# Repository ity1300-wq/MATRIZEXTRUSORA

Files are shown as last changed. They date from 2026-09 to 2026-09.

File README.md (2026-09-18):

# MATRIZEXTRUSORA — Matriz Jonatha (Extrusão Plana Master Aprovado)





## ✅ O modelo oficial agora é a **v29.0 — peça única** (2026-09-13)

> Decisão do dono: *"a peça única vira a oficial, também quero todos os materiais e informações para deixar ela
> pronta para usinagem"*.

| | |
|---|---|
| **peça** | `07_CAD_Matrizes/Matriz_Jonatha_v29_OFICIAL/MATRIZ_V29_PECA_UNICA.step` (sha256 `ffa6cc4baa6496c4…`), atalho em `01_CAD_MatrizJonatha_Oficial/MatrizJonatha_v29_PECA_UNICA.step` |
| **o que é** | a v27.0 com as duas metades unidas em **um sólido**: 22 faces, 1 casca, 469.303,2 mm³ de aço (3,6840 kg), canal de 213.945,1 mm³ **idêntico ao master**, 0,00 % de sombra no canal |
| **o que NÃO mudou** | nenhum byte dos arquivos selados: `07_/Matriz_Jonatha_v27_OFICIAL/` e `01_/MatrizJonatha.step` seguem como estavam (o portão confere o sha256 contra o baseline do auditor) — a promoção é declarada aqui, no SSOT (`matriz_oficial`) e no índice de `07_/`, não escrita por cima do histórico |
| **para a fábrica** | `08_Pacote_Usinagem_v29/` — ficha de fábrica, material e tratamento, sequência de usinagem, tabela de tolerâncias e inspeção, RFQ pronto, prancha 2D cotada, os 3 STEP e `CHECKSUMS_SHA256.txt` |
| **geração** | `python3 04_Dados_SSOT_e_Scripts/gerar_pacote_usinagem_v29.py` — toda cota do pacote é medida no STEP, nada digitado |
| **por que 109 mm e não 100** | `03_Relatorios_e_Documentacao/SIMULACAO_ROTAS_E_COMPRIMENTO.md`: encurtar a peça não mexe no funil nem no land (as cotas que geram pressão) e encurta a rota de fuga pelo anel — a fração que escapa para trás sobe de 0,067 % para 0,071 % |




Projeto de engenharia mecânica, reologia computacional (CFD) e modelagem 3D CAD para fabricação da **Matriz Jonatha**: matriz de extrusão plana otimizada para manta de isolação de acessórios de cabos elétricos de Média Tensão (MT).

> **Voltando de uma sessão perdida (ou assumindo com outro agente)?** Leia [`CONTINUIDADE.md`](CONTINUIDADE.md)
> na raiz: é o estado do trabalho, as regras que valem, como montar o ambiente, o que o dono do projeto já
> decidiu e o que está pendurado. Ele + `git log` substituem a conversa — nada importante vive só no chat.

---

## 📌 Especificação Resumida do Produto Final
- **Largura da Manta ($X$):** $75,00\text{ mm}$ (Constante de ponta a ponta)
- **Espessura da Manta ($Y$):** $1,50\text{ mm}$
- **Perfil das Bordas Laterais:** Raio Total $R = 0,75\text{ mm}$ (elimina concentração de campo elétrico em cabos MT)
- **Chanfro de Saída:** $1,50\text{ mm} \times 45^\circ$ no v27.0 aprovado → **reduzido para $0,80\text{ mm} \times 45^\circ$ na proposta v28.0**, o que devolve 0,70 mm de land reto (8,50 → 9,20 mm) e engrossa a lâmina do lábio de 0,75 → 1,45 mm (medido)
- **Encaixe de Entrada ($Z=0$):** Restrito ao diâmetro de acoplamento da extrudora ($\varnothing 75,60\text{ mm}$), garantindo vedação e montagem perfeita.
- **Envelope Cilíndrico Externo:** Estágio 1 ($\varnothing 93,00 \times 69,90\text{ mm}$), Estágio 2 ($\varnothing 89,50 \times 10,80\text{ mm}$), Estágio 3 ($\varnothing 79,50 \times 28,30\text{ mm}$) — 100% idêntico à Matriz 2 para montagem direta na máquina.

---

## 📊 Resultados da Simulação Reológica CFD (Matriz 2 vs. Matriz Jonatha Master Aprovado)

| Métrica Reológica | Matriz 2 (Matriz Gedeon) | **Matriz Jonatha Master (v27.0)** | Ganho / Melhoria |
| :--- | :---: | :---: | :---: |
| **Geometria do Canal Interno** | Funil abrupto + Fenda de $87,60\text{ mm}$ | **Funil V Restrito na Entrada** + Land $10\text{ mm}$ | **Redução de $88.6\%$ no land** |
| **Perda de Carga Total ($\Delta P$)** | **$268,7\text{ bar}$** | **$68,2\text{ bar}$** | **Redução de $74,6\%$ na contrapressão** |
| **Uniformidade de Velocidade** | $68,96\%$ (falta vazão nas pontas) | **$99,10\%$** | **Fluxo $100\%$ plano e homogêneo** |
| **Tensão de Cisalhamento na Parede** | $157,11\text{ kPa}$ | **$128,44\text{ kPa}$** | **Operação suave sem fratura do fundido** |
| **Qualidade da Manta** | Rasgos e afinamento nas bordas ao esquentar | **Bordas perfeitas sem rasgos** | **Eliminação de refugos de produção** |

> ⚠️ **Leitura obrigatória desta tabela (auditoria de 2026-09-11).** Os valores acima são saída de
> CFD arquivada e **não são reproduzíveis a partir dos arquivos deste repositório** (não há malha,
> caso nem planilha). Medindo a geometria real dos STEP: ΔP 1D **41,9 bar** na v27.0 e **43,9 bar** na
> v28.0 (não 68,2 bar), e a **tensão de cisalhamento na parede é a mesma nas duas matrizes
> (163,8-164,0 kPa)** — a linha "157,11 → 128,44 kPa" não se sustenta, pois fenda e vazão são
> idênticas. A **uniformidade de 99,10 %** não tem definição nem dados anexados: não usar como
> critério de aceite. Ver `03_Relatorios_e_Documentacao/TRIAGEM_DE_PROBLEMAS_DAS_MATRIZES.md`.

---

## 📐 Revisão v28.1 — proposta DFM verificada (não substitui o v27.0)

A v27.0 continua sendo o **master aprovado**; a v28.0 vive ao lado, em arquivos novos, até a
aprovação. Ela resolve o que a auditoria apontou como defeito real e prova cada número medindo os
sólidos (booleanos + `BRepExtrema`), não declarando:

| | v27.0 aprovado | v28.1 proposta |
| :--- | :--- | :--- |
| Land reto e paralelo | 8,50 mm (o SSOT declarava 10,00) | **8,50 mm — mantido** (D2); SSOT corrigido para 8,50 + 1,50 de chanfro |
| Chanfro de saída | 1,50 × 45° (lâmina de 0,75 mm) | **1,50 × 45° — mantido** (a redução para 0,80 foi rejeitada em D2); boca de saída medida 78,00 × 4,50 mm |
| Furos de pino | 2 bolsões **selados** no Body_A; nenhum no Body_B | **4 bolsões Ø4 H7 × 12 abertos no plano de partição, conjugados nas duas metades** + kit de pinos |
| Aquecimento | nenhum | **6 cartuchos Ø9,5** (Z=97,00; X=0 e ±22) e **4 poços de termopar Ø4,8** (Z=103,00; X=±11), paredes reais de 2,39-17,03 mm |
| Arquivo do canal | 3 sólidos (núcleo + 2 bolhas) | **1 sólido** (pronto para EDM e para malha de CFD) |
| Especificação do produto | 75,00 × 1,50 mm, R0,75, boca Ø75,60, envelope Ø93/89,5/79,5 × 109,00 | **idêntica e re-medida: Δ máximo = 0,000000 mm** |

- Verificação: **64 itens medidos, 64 conformes, 0 não conformes** → `03_Relatorios_e_Documentacao/VERIFICACAO_V28.md`
- Memória de cálculo, cotas de usinagem, o que **não** cabe (fixação das metades e refrigeração) e as
  decisões pendentes → `03_Relatorios_e_Documentacao/PROJETO_DFM_V28_MATRIZ_JONATHA.md`
- Conferência visual (6 vistas geradas dos STEP) → `03_Relatorios_e_Documentacao/V28_CONFERENCIA_VISUAL.png`
- Descoberta registrada: o funil do modelo aprovado é um **cônico linear de largura constante**, não o
  "coat-hanger com reservatório de 6,00 mm" descrito — as seções intermediárias do loft nunca entraram
  no sólido. Item de decisão **D3**.

### 🧪 Variantes em estudo (não são o modelo oficial)

`05_Variantes_Em_Estudo/` guarda os STEP de comparações pedidas antes de qualquer mudança de geometria.
Hoje há uma: o **funil coat-hanger** medido contra o cone linear do master (ΔP 1D, tempo de residência,
volume estacionado nas pontas, invasão do envelope e aço cortado) — tabela e leitura em
`03_Relatorios_e_Documentacao/ESTUDO_FUNIL_COATHANGER.md`, gerador em `04_Dados_SSOT_e_Scripts/estudar_funis.py`.
Nada disso substitui `MatrizJonatha.step`.

### ✅ Porta de verificação

`verificar_cadeia.py` roda a cadeia inteira e depois cobra 7 invariantes: contagens dos verificadores,
o único não conforme esperado da interface, as medidas do STEP do cabeçote, **os números que os
documentos citam contra os JSON gerados** (foi assim que 1372→2744 e 14,3→14,00 apodreceram), a
ausência de cópia manual de número de booleano e as regras 1 e 2 (v27.0 e `02_CAD_Modelos_Historicos/`
intactos). Sai com código 1 se qualquer uma falhar — e ela foi auto-testada injetando o número velho.

### 📐 Parte interna do cabeçote × as cinco matrizes (comparado por medida)

`03_Relatorios_e_Documentacao/INTERFASE_INTERNA_CABECOTE_X_MATRIZES.md`, gerado por
`04_Dados_SSOT_e_Scripts/medir_perfis_matrizes_x_cabecote.py`, mede a escada de cada matriz nos STEP
dela (Copo original, Gedeon, Desenvolvimento, Jonatha v27.0, v28.1) e o posiciona no cabeçote pelos três
encostos possíveis, com interferência medida por booleano. Resultado central, medido hoje: as cinco têm o
fim da banda Ø93 no **mesmo Z** e a mesma folga axial no degrau; a Copo não tem nariz e por isso fica com a
face de saída **enterrada**, enquanto Gedeon/Desenvolvimento/Jonatha protrudem — a diferença de comprimento
é exatamente o nariz, somada aos dois deslocamentos de face. O relatório traz também o que-if do chanfro no
canto interno Ø90 → Ø80, medido contra as cinco, como proposta (não é mudança aprovada no desenho).

### 🔧 Cabeçote em STEP (peça da máquina, não da matriz)

`06_CAD_Cabecote_EX-030/STEP/` guarda quatro STEP e um PDF: os dois sólidos do cabeçote, o cabeçote
com a **Matriz 1 Copo** sentada e o cabeçote com a **Matriz 2 Gedeon** sentada (arquivos compostos, 2
sólidos no mesmo referencial, interferência medida 0,0000 mm³ nos dois), e `DESENHO_2D_CABECOTE_X_MATRIZES.pdf`
— vista lateral em corte do cabeçote e de cada matriz com as cotas principais, gerado a partir dos próprios
STEP. O encosto do conjunto na máquina é **face a face** (face do flange na face da extrusora), o que exige
3,00 mm de rebaixo na máquina para receber o piloto Ø105 × 3,00; a posição axial da matriz não muda com
isso, porque ela vem do degrau e do fundo do bolso do cabeçote. O entregável é o
cabeçote **sem a parte que conecta na extrusora** — a interseção pelo
cilindro Ø130 do corpo, que leva o chanfro 10 × 45° da transição corpo→flange (Ø130 → Ø150, cota que
estava no desenho e no SSOT mas ainda não no sólido), o flange Ø220 × 40 com os 6 × Ø16,5 e o piloto de
centragem **Ø105 × 3,00 mm** atrás do flange — que é o que fecha o total em 95,00 mm (o "ressalto Ø203 × 3"
que estava aqui era leitura minha do bordo externo das fendas de 23,5: r = 101,5 = 90 + 11,75). Massas,
volume, metal removido na banda Ø93, comprimento e interferência com `MatrizJonatha_v28.step` são lidos do
sólido a cada rodada e publicados em `04_Dados_SSOT_e_Scripts/cabecote_step.json` — não são copiados para cá
porque cópia manual de número de booleano apodrece. Não é peça de produção: sem o flange não há onde
aparafusar a junta, e o M12 transversal ficou fora do modelo por indeterminação de desenho — tudo em
`03_Relatorios_e_Documentacao/CABECOTE_EX-030_STEP.md`.

### 🔩 Interface com o cabeçote EX-030 — medida no DWG e provada nos sólidos

O `030-032- cabeçote.dwg` (HIDEALL, PED:2257) foi convertido e **medido entidade por entidade**. A
escala do desenho foi calibrada pelas próprias cotas (**25,534 mm por unidade DXF**, 5 fechos
independentes fechando em 0,012 %), e o sólido do cabeçote montado a partir dessa medição foi
enfrentado à v28.0 com booleanos: **43 itens, 39 conformes, 0 não conformes, 4 pendências do lado
da máquina** → `03_Relatorios_e_Documentacao/INTERFASE_CABECOTE_EX030.md`

| o que foi medido | resultado |
| :--- | :--- |
| furos do cabeçote para a matriz | Ø80,00 × 14,00 · Ø90,00 × 11,00 · Ø95,00 × 70,00 (profundidade da face do nariz) |
| encaixe nos 3 estágios da matriz | folga radial **1,00 / 0,25 / 0,25 mm**, folga axial no degrau de apoio **0,10 mm**, interferência **0,0000 mm³** |
| face do cabeçote | anel de **20,00 mm** (Ø90 → Ø130); nariz Ø80 maior que a fenda (75,80) e menor que a matriz (Ø93) |
| protrusão da matriz | face de saída **14,00 mm** à frente do nariz do cabeçote — a fenda trabalha fora da peça aquecida |
| fixação | bucha cônica **EX-031** (Ø95 → Ø86, cone 3,00°, L 70,00) apertando a banda Ø93: **8,58 MPa** fecham os 55,7 kN da partição; empuxo axial de 29,85 kN recai no degrau, no anel de contato real de 431,2 mm² (**69,22 MPa**, margem 20,2×) |
| padrão de flange (P4) | **não existe na matriz**: 6 × Ø16,50 em fendas de 23,50 sobre C.C. Ø180,00 (M12, ±7,20° de ajuste) é a junta cabeçote ↔ extrusora, a 35,25 mm do corpo da matriz |
| **bloqueio** | anel do nariz **Ø68,30** (carimbo 9"×65 mm) → 5,60 mm de interferência radial por lado com o nariz Ø79,50 da matriz: **a matriz de 75 mm não monta com esse anel**, e como o furo do nariz já é Ø80 não há espaço para nenhum anel não restritivo |

Correção registrada: a triagem anterior calibrou a escala em "C/G Ø150" (k = 21,28 mm/un) lido em
raster de baixa resolução e sugeriu grampos nesses furos. O desenho diz **C.C Ø180**; os furos são
da junta com a extrusora e **a recomendação de grampos no flange foi retirada** — a fixação vem do
collete da própria máquina. Nenhuma cota da matriz mudou por causa disso: o envelope
Ø93/Ø89,50/Ø79,50 × 109,00 é exatamente o centragens do cabeçote.

```bash
python 04_Dados_SSOT_e_Scripts/gerar_matriz_v28.py               # regenera os STEP v28.0
python 04_Dados_SSOT_e_Scripts/verificar_v28.py --json --md      # volta a medir e provar
python 04_Dados_SSOT_e_Scripts/explorar_acomodo_furos.py --json # onde existe aço para furos
python 04_Dados_SSOT_e_Scripts/gerar_relatorio_v28.py           # atualiza o relatório com os dados
python 04_Dados_SSOT_e_Scripts/renderizar_v28.py --saida v28.png
python 04_Dados_SSOT_e_Scripts/verificar_interface_cabecote.py --json --md  # matriz × cabeçote EX-030
python 04_Dados_SSOT_e_Scripts/gerar_cabecote_ex030.py                 # STEP do cabeçote sem a junta, e as 2 montagens
python 04_Dados_SSOT_e_Scripts/gerar_desenho_2d_cabecote_matriz.py      # o PDF 2D (corte + cotas) das peças
python 04_Dados_SSOT_e_Scripts/verify_geometry_ssot.py --json --md     # a AUDITORIA (issue/PR #1) e seu tratamento
python 04_Dados_SSOT_e_Scripts/verificar_cadeia.py --com-estudos       # A PORTA: roda tudo e cobra as 7 checagens
```

### 🔎 O processo de auditoria (issue e PR #1) e para onde ele aponta

A auditoria dimensional automatizada dos STEP oficiais vive em `04_Dados_SSOT_e_Scripts/verify_geometry_ssot.py`
(relatório: `03_Relatorios_e_Documentacao/AUDITORIA_GEOMETRICA_MATRIZ_JONATHA.md`, dados:
`04_Dados_SSOT_e_Scripts/auditoria_geometrica.json`) e é a PR #1 / issue #1 do repositório. A seção **6** do
relatório é o relato contra cada achado (G-01 … G-06 e as ações 6 e 8 do plano): status, o que foi feito, o
número medido hoje e onde o número é re-medido. Ela é **gerada** a partir de
`04_Dados_SSOT_e_Scripts/cad_die_parameters.json:audit.tratamento_auditoria_v28_1` — não é texto solto que
possa apodrecer do lado de lá do SSOT. O que continua aberto está listado no fim da mesma seção.

---

## 📂 Estrutura Direta de Pastas do Repositório

```
MATRIZEXTRUSORA/
├── README.md                              -> Este arquivo guia do repositório
├── .gitignore                             -> Exclusões para repositório Git
│
├── 📂 07_CAD_Matrizes/                     -> **UMA PASTA POR MATRIZ** (reorganização de 2026-09-13)
│   ├── Matriz_Jonatha_v27_OFICIAL/           -> o modelo oficial: MatrizJonatha.step, A, B, canal, explodida,
│   │                                        com fluxo — e o README com o sha256 conferido contra o baseline
│   ├── Matriz_Jonatha_v28_1_PROPOSTA/          -> proposta DFM v28.1 (NÃO promovida): A/B, canal, kit de 4 pinos
│   ├── Matriz_Gedeon_Certa/                  -> a Gedeon do backup do usuário, partida em Y = 0, + prancha de
│   │                                        5 faixas `DESENHO_2D_GEDEON_CERTA_X_JONATHA.pdf`
│   ├── Matriz_Gedeon_Entregue_HISTORICA/     -> os 4 STEP da Gedeon do CAD antigo + README com a medição que
│   │                                        serve de contraste (a "Gedeon corrigida" foi APAGADA em
│   │                                        2026-09-13: a certa é o arquivo do usuário, não havia canal a
│   │                                        reconstruir)
│   ├── Matriz_Copo_HISTORICA/                -> os 6 STEP da Matriz 1 "Copo" + README
│   ├── Matriz_Desenvolvimento_HISTORICA/     -> os 5 STEP da matriz de desenvolvimento + README
│   └── README.md                             -> índice das pastas, por que os caminhos antigos valem e o que
│                                                foi removido (com o comando que recria cada derivado)
│
├── CONTINUIDADE.md                           -> COMO RETOMAR O TRABALHO: estado, ambiente, portão, pendências
│
├── 📂 01_CAD_MatrizJonatha_Oficial/       -> caminho oficial (SSOT v27.0). Desde 2026-09-13 os seis
│   └── MatrizJonatha*.step                 `MatrizJonatha*.step` são SYMLINKS para
│                                            `07_CAD_Matrizes/Matriz_Jonatha_v27_OFICIAL/`, para que o caminho
│                                            citado por auditoria, CI e CODEOWNERS ache os mesmos bytes. Os
│                                            arquivos físicos moram na pasta da matriz: a regra 1 é sobre o
│                                            MODELO, e o portão confere o sha256 contra o baseline.
│
├── 📂 02_CAD_Modelos_Historicos/          -> MODELOS CAD LEGADOS PRESERVADOS (regra 2: ler sim, editar não)
│   ├── MatrizGedeon.step e variantes     -> Matriz 2 (Gedeon) original: SYMLINK para a pasta dela em 07_;
│   │                                        os bytes são os selados no baseline do auditor (regra 2 é sobre
│   │                                        os modelos, não sobre o caminho)
│   ├── MatrizDesenvolvimento.step        -> Versão intermediária (symlink)
│   ├── Matriz1_Original_Copo.step        -> Matriz 1 (Copo Oco) (symlink)
│   └── matrizGedeonCerta.step            -> **o arquivo do usuário**: a Gedeon CERTA, entregue como veio
│                                            (1 sólido, 640.180,7 mm³); cópia byte a byte em 07_/Matriz_Gedeon_Certa/
│
├── 📂 03_Relatorios_e_Documentacao/       -> DOCUMENTAÇÃO TÉCNICA E SIMULAÇÕES
│   ├── AUTO_PROMPT_CONTINUIDADE_MATRIZ_JONATHA.md -> Prompt de handover para continuidade em IA
│   ├── AUDITORIA_GEOMETRICA_MATRIZ_JONATHA.md -> Auditoria dimensional automática dos STEP vs. SSOT
│   ├── TRIAGEM_DE_PROBLEMAS_DAS_MATRIZES.md -> O que é problema real e o que não é, nas 4 matrizes
│   ├── PROJETO_DFM_V28_MATRIZ_JONATHA.md  -> Memória de cálculo e cotas da revisão v28.0
│   ├── VERIFICACAO_V28.md                 -> As 64 medições que provam a v28.0
│   ├── AVALIACAO_MELHORIA_MATRIZ_3_JONATHA.md -> Avaliação independente, com CFD 2D próprio: a
│   │     Matriz 3 pode melhorar? (figuras/aresta_R075_intuicao.png: por que a aresta R0,75 recebe pouco material)
│   ├── RELATORIO_GEDEON_CERTA.md          -> A Gedeon do usuário medida face por face, e o que se achou nela
│   ├── INTERFASE_INTERNA_CABECOTE_X_MATRIZES.md -> O que tem dentro do furo do cabeçote, medido nos STEP
│   ├── AUDITORIA_CORRELACOES_STEP.md       -> os 64 STEP cruzados em sete correlacoes, medidos no arquivo
│   ├── REOLOGIA_MASTIC_EPDM.md            -> a banda de reologia do mastique resistivo de EPDM (literatura)
│   └── FONTES_DO_USUARIO_2026-09-13.md    -> as 8 capturas dele, com sha256, e por que ficaram fora
│   ├── RELATORIO_DE_SIMULACAO.md          -> Relatório executivo completo de CFD reológico e térmico
│   ├── CAD_SPECIFICATION_BACKUP_SSOT.md  -> Especificação técnica unificada SSOT v27.0
│   └── SIMULACAO_REOLOGICA_MATRIZ_JONATHA.md -> Detalhamento dos modelos reológicos
│
└── 📂 04_Dados_SSOT_e_Scripts/            -> PARÂMETROS NUMÉRICOS E GERADORES
    ├── cad_die_parameters.json            -> JSON da Fonte Única da Verdade (SSOT v27.0)
    ├── auditoria_geometrica.json          -> Resultado numérico da auditoria dimensional dos STEP
    ├── verify_geometry_ssot.py            -> Auditoria automática: mede os STEP e compara com o SSOT
    ├── verify_legacy_dies.py              -> Mede as 4 matrizes, confere os arquivos e recalcula o ΔP
    ├── auditoria_matrizes_historicas.json -> Resultado numérico da comparação entre as 4 matrizes
    ├── gerar_matriz_v28.py                -> Gerador da revisão v28.0 (lê o canal aprovado, não re-desenha)
    ├── verificar_v28.py                   -> Verificador exato da v28.0 (64 medições, 0 NC)
    ├── gerar_relatorio_v28.py             -> Monta o relatório DFM a partir dos JSONs medidos
    ├── explorar_acomodo_furos.py          -> Mapeia o aço disponível para furos antes de fixar cotas
    ├── renderizar_v28.py                  -> Render headless de conferência (matplotlib, sem GPU)
    ├── matriz_v28_features.json           -> Cotas de projeto dos 14 furos (fonte do verificador)
    ├── verificacao_v28.json               -> Resultado numérico das 64 medições
    ├── acomodo_furos.json                 -> Grade de posições viáveis por tipo de furo
    ├── generate_auto_prompt.py            -> Gera o prompt de handover a partir do SSOT
    ├── setup_headless_gl.sh               -> Ambiente CAD headless (stub libGL para servidores/CI)
    ├── setup_cfd_env.sh                   -> Ambiente CAD+CFD completo (cadquery, gmsh, scikit-fem, pyamg)
    ├── cfd_land_crosssection.py           -> CFD 2D por seção transversal (p-Laplaciano, P2) — validado 0,6%
    ├── cfd_edge_relief.py                 -> Canal paramétrico com alívio de borda (estudo de sensibilidade)
    ├── avaliacao_matriz3_calculos.py      -> Perfil de pressão, mecânica, residência, inchamento, sensibilidade
    ├── avaliacao_matriz3_uniformidade.py  -> Uniformidade transversal da vazão a partir do CFD
    ├── avaliacao_matriz_3_secoes.json     -> CFD 2D das seções (Matriz 3)
    ├── avaliacao_matriz_3_calculos.json   -> Cálculos de engenharia consolidados (Matriz 3)
    ├── avaliacao_matriz_3_uniformidade.json -> Métricas de uniformidade transversal (Matriz 3)
    ├── avaliacao_matriz_3_alivio_borda.json -> Estudo paramétrico de alívio de borda
    ├── dados_simulacao_reologica.json     -> Dados numéricos de simulação em JSON
    ├── dados_simulacao_carreau_yasuda.json -> Dados numéricos térmicos em JSON
    ├── verificar_cadeia.py                -> **O PORTÃO**: re-rodá os geradores, confere documento × JSON,
    │                                        sha256 dos selos e as regras 1 e 2 (`--rapido` só consulta)
    ├── cabecote.dxf.xz                    -> O DXF do croquis do cabeçote (6,8 MB) compactado (0,58 MB):
    │                                        entrada de `medir_perfil_cabecote.py`, que descompacta sozinho
    ├── gerar_gedeon_certa.py              -> Mede o arquivo do usuário e escreve JSON + relatório (21 checks)
    └── desenhar_gedeon_consertada.py      -> A prancha de 5 faixas (o nome sobrou do episódio da refutada)

├── 📂 05_Interface_Auditoria/              -> O CONTRATO: protocolo, baseline selado, propostas e vereditos
│                                            (zona congelada — quem propõe não edita aqui)
└── 📂 06_CAD_Cabecote_EX-030/STEP/          -> O cabeçote e as montagens cabeçote + matriz: `Cabecote_EX-030_
                                             sem_flange.step`, `_desenhado.step`, `_com_Matriz_Copo.step`,
                                             `_com_Matriz_Gedeon.step`, `_com_Matriz_Gedeon_Certa.step` e o PDF
                                             2D do conjunto. A matriz tem pasta; o conjunto é outra.
```

---

## 🤝 Interface de Auditoria (IA engenheira ⇄ IA auditora)

O projeto tem um **contrato versionado** para que uma IA de projeto proponha melhorias e uma IA
auditora verifique — sem conversa, sem ambiguidade e sem número sem lastro:

```
05_Interface_Auditoria/
├── PROTOCOLO_AUDITORIA.md        contrato: papéis, ciclo, estados, severidades, tolerâncias
├── esquema/proposta.schema.json  o que a IA engenheira entrega
├── esquema/veredito.schema.json  o que a IA auditora devolve
├── scripts/auditar_proposta.py   auditor: mede os STEP, recalcula e emite o veredito
├── propostas/PRP-XXXX-*.json     propostas de engenharia (uma por iteração)
├── vereditos/PRP-XXXX.{json,md}  vereditos (contrato + comentário de PR)
└── baseline/MATRIZ_3_v27.json    estado aprovado congelado, para comparar evolução
```

**Regra fundadora:** *nenhum número entra no projeto sem um script que o reproduza.* Toda afirmação
numérica é uma **proposta**; todo número medido é um **veredito**.

```bash
# congelar o estado atual como baseline (só quando o modelo muda de versão)
python 05_Interface_Auditoria/scripts/auditar_proposta.py --congelar-baseline

# auditar uma proposta (leve, ~2 min)
python 05_Interface_Auditoria/scripts/auditar_proposta.py \
       05_Interface_Auditoria/propostas/PRP-0001-land-10-chanfro-08.json --json --md

# com CFD 2D na auditoria (~8 min)
python 05_Interface_Auditoria/scripts/auditar_proposta.py <proposta.json> --com-cfd --json --md
```

Estados do veredito: **APROVADO** · **APROVADO_COM_RESSALVAS** · **REPROVADO** (número declarado ≠
recalculado, ou métrica degradou) · **BLOQUEADO** (requisito duro violado: largura, espessura, borda,
envelope, arquivos, zona congelada).

Quatro formas de operar, todas implementadas (detalhes no `PROTOCOLO_AUDITORIA.md` §7):

| Modo | Ferramenta | Latência |
| :--- | :--- | :--- |
| A — CI | `.github/workflows/auditoria.yml` — pronto em `05_Interface_Auditoria/ci/auditoria.yml`, aguardando permissão `workflows` do app (comenta no PR) | ~6 min |
| B — vigilância git | `python 05_Interface_Auditoria/scripts/monitor_auditoria.py [--remoto --push]` | ~2 min/proposta |
| B — painel vivo | `python 05_Interface_Auditoria/scripts/painel_auditoria.py --porta 8000` | segundos |
| C — ponte humana | colar a proposta no chat e receber o veredito | minutos |

O painel vivo é também uma API para a IA engenheira:

```bash
curl -X POST 'http://localhost:8000/api/auditar?modo=completo&sincrono=1' \
     -H 'Content-Type: application/json' --data-binary @proposta.json   # -> veredito em JSON
```

---

## 🔍 Auditoria Geométrica dos Arquivos STEP

Os entregáveis CAD são verificados automaticamente contra o SSOT (não por inspeção visual,
mas medindo as seções dos sólidos STEP):

```bash
bash 04_Dados_SSOT_e_Scripts/setup_headless_gl.sh   # apenas em servidores sem libGL
export LD_LIBRARY_PATH="$PWD/04_Dados_SSOT_e_Scripts/.headless_gl:$LD_LIBRARY_PATH"
python 04_Dados_SSOT_e_Scripts/verify_geometry_ssot.py --json --md
```

```bash
python 04_Dados_SSOT_e_Scripts/verify_legacy_dies.py --json   # compara as 4 matrizes
```

## 💧 CFD próprio (validado)

O repositório traz um solucionador próprio de CFD 2D de escoamento desenvolvido (p-Laplaciano de lei
das potências, elemento P2), com a malha gerada do STEP oficial pelo gmsh:

```bash
bash 04_Dados_SSOT_e_Scripts/setup_cfd_env.sh
export LD_LIBRARY_PATH="$PWD/04_Dados_SSOT_e_Scripts/.headless_gl:$LD_LIBRARY_PATH"
python 04_Dados_SSOT_e_Scripts/cfd_land_crosssection.py --secoes 70 95 99.5 103 107 --json
python 04_Dados_SSOT_e_Scripts/avaliacao_matriz3_calculos.py --json
python 04_Dados_SSOT_e_Scripts/avaliacao_matriz3_uniformidade.py --json
```

O integrador 1D deste repositório (`verificar_v28.py`) bate com esse CFD: τ de parede no land **163,8 kPa** contra **160,9 kPa** do 2D — 1,8 % de diferença, e é esse par de números que a seção 6 da auditoria cita.

Validação: gradiente no land medido em **2,1761 bar/mm** contra **2,189 bar/mm** da solução analítica
de lei das potências (0,6%) — o mesmo valor é reproduzido pelo integrador 1D do STEP e pelo canal
paramétrico. Limitações (viscoelasticidade, superfície livre e canal 3D completo) estão declaradas em
`03_Relatorios_e_Documentacao/AVALIACAO_MELHORIA_MATRIZ_3_JONATHA.md`.

Última execução (v27.0): **36 itens verificados, 19 conformes, 2 não conformes, 15 informativos**
— as 2 não conformidades continuam abertas de propósito: são exatamente os itens que a v28.1 fecha
(land declarado vs. real e cavidades seladas / furos só num corpo).
Resultado completo em `03_Relatorios_e_Documentacao/AUDITORIA_GEOMETRICA_MATRIZ_JONATHA.md` e
diagnóstico comparativo em `03_Relatorios_e_Documentacao/TRIAGEM_DE_PROBLEMAS_DAS_MATRIZES.md`.

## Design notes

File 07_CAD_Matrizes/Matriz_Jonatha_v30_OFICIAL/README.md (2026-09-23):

# Matriz JONATHA — v30 (revisão de 2026-09-22)

Peça única (1 sólido, 1 casca, 22 faces, BRep válido). **Não é a v27.0 bipartida**: é o mesmo canal de fluxo do master, com o envelope alterado por decisão do dono em 2026-09-22 e tolerância **±0,5** em toda cota alterada.

| cota | medida no STEP |
|---|---|
| Ø 1º estágio (datum A) | 94,00 mm em Z 0,00 → 69,90 |
| Ø 2º estágio | 89,00 mm em Z 69,90 → 80,70 |
| Ø 3º estágio | 79,00 mm em Z 80,70 → 95,00 |
| comprimento total | 95,00 mm |
| fenda no land | 75,0000 × 1.500 mm, R 0,75 nas pontas (área 112,0171 mm²) |
| land paralelo | 8.500 mm (Z 85,00 → 93,50) |
| chanfro de saída | 1,50 × 45°, cone medido em Z 93,50 → 95,00 |
| boca de entrada | Ø75,60 (restrita por contrato) |
| volume de aço | 438509,9 mm³ → 3,4423 kg |
| canal de fluxo | 183862,6 mm³ (229,8 g de mastique dentro) |
| material | aço 1045 + indução (ou nitretação a plasma) nas arestas do land |

## Interface com o EX-030 (medida na montagem)

| estágio da matriz | furo do cabeçote | folga radial | Z congruente |
|---:|---:|---:|---|
| Ø94,00 | Ø95,00 | 0,50 mm | 0,00 → 69,90 |
| Ø89,00 | Ø90,00 | 0,50 mm | 70,00 → 80,70 |
| Ø79,00 | Ø80,00 | 0,50 mm | 81,00 → 95,00 |

Encosto face a face, `deslocamento_aplicado_mm` = 0,00 · **interferência 0,0000 mm³** · face de saída no Z 95,00 · **protrusão além do nariz +0,00 mm** (a face do nariz está em Z 95,00).

## Arquivos

| arquivo | o que é | sha256 |
|---|---|---|
| `MATRIZ_V30_PECA_UNICA.step` | **a peça** (o que a fábrica usina) | `b42ee2e50a10d43d` |
| `MATRIZ_V30_CANAL_DE_FLUXO.step` | o sólido do canal de fluxo (para o fio EDM e para conferir o volume) | `77497bf86c989b23` |
| `CONJUNTO_MATRIZ_V30_NO_CABECOTE_EX-030.step` | a matriz sentada no cabeçote completo, com flange (leitura/medida, sem booleano) | `725c2f83f26cc6e8` |
| `08_Pacote_Usinagem_v30/` | pacote de usinagem vigente (ficha, material, cotas, sequência, RFQ, prancha) | zip `0738c4683c80efdb` |

O que mudou em relação à revisão anterior está anotado em `03_Relatorios_e_Documentacao/MATRIZ_V27_PECA_UNICA.md` (seção de 2026-09-22) e no SSOT (`decisoes_usuario` D10 a D12). Para a fábrica, a peça continua se chamando **JONATHA v27.0**; 'v29'/'v30' é carimbo interno de revisão do projeto.

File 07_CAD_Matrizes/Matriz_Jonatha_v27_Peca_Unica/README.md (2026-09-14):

# Matriz Jonatha v27.0 como **peça única** (variante derivada — não é o master)

Pedido em 2026-09-13: "transforme a peça matriz JONATHA V27 em peça única, não bipartida". O master continua
`../Matriz_Jonatha_v27_OFICIAL/MatrizJonatha.step` (sha256 `7f26c5c5ba238a12…`, regra 1: nunca editado; o
portão confere isso por conteúdo). Esta pasta é a variante.

| arquivo | o que é |
|---|---|
| `MatrizJonatha_v27_Peca_Unica.step` | **1 sólido, 1 casca, 22 faces**, sha256 `ffa6cc4baa6496c48e1f985f088e605c84588e24bb1f888fc106c37eaca15295` |
| `peca_unica_v27.json` | todas as medidas, a visibilidade das 17 caras do canal e a montagem |

Recriar do zero (lê o master, junta as metades, fecha as bolhas seladas, mede, monta):

    python3 04_Dados_SSOT_e_Scripts/gerar_matriz_v27_peca_unica.py

## O que a peça única tem de diferente, medido

* **aço:** 469.303,2 mm³ (3,684 kg) contra 469.001,7 mm³ das duas metades — os **+351,9 mm³** são as duas
  cavidades seladas dos furos de pino, que deixam de existir porque não há mais o que alinhar;
* **canal idêntico:** 213.945,1 mm³ nas duas peças (funil + fenda), medido como envelope − aço;
* **produto idêntico:** fenda 75,000 × 1,500 mm com R 0,75 no land (Z = 107,00), boca de saída 78,00 × 4,50 mm
  pelo chanfro 1,50 × 45° (decisão D2 preservada), boca de entrada Ø 75,60 mm, envelope Ø 93,00 / Ø 89,50 /
  Ø 79,50 com Z total 109,00 mm;
* **topologia limpa:** BRepCheck válido no sólido e em **0** de 22 faces e **0** de 90 arestas (é o exame que
  reprovou o `Body_B` da v28.1);
* **linha de partição: zero.** Na bipartida o plano Y = 0 cruza o canal (seção de 8.204,4 mm², 78,00 × 109,00 mm,
  perímetro de costura 372,8 mm) e corre pelas **duas bordas** da manta — é o caminho por onde sai degrau e
  rebarba na borda. Somem também os 759,5 mm² de contato metal-metal entre as metades e a força de abertura de
  55,7 kN que os pinos tinham de segurar.

## Fabricabilidade (o motivo real de a peça ser bipartida)

Cada uma das 17 caras do canal foi testada contra linha reta vinda da entrada (Z < 0) e da saída (Z > 109,00),
com folga de 0,60 mm para dentro do vazio e raio de teste de 0,10 mm. **Nenhuma cara ficou em sombra: 0,0 mm² de
25.181,8 mm² de superfície de canal (0,00 %).** Os dois flancos do funil (9.184 e 9.213 mm², BSPLINE) só são
vistos pela **entrada** — passam pelo Ø 75,60 —, as paredes da fenda e o chanfro são vistos pela **saída**, e as
duas bordas em R 0,75 são vistas dos dois lados. Ou seja: a peça única é usinável com ferramenta entrando pelas
duas faces (fresa/EDM pelo lado da extrusora para o funil em V, brocha ou EDM pela face de saída para a fenda),
**sem junta**. O que a bipartição resolvia não era sombra geométrica, era conveniência de máquina: fenda de 1,5 mm
brochada ou queimada em 109 mm de profundidade é a operação cara desta peça.

## Cabeçote

`../../06_CAD_Cabecote_EX-030/STEP/Cabecote_EX-030_com_Matriz_Jonatha_v27_Peca_Unica.step` — cabeçote completo
com flange + a peça única, 2 sólidos, interferência 0,0000 mm³, saída em Z = 109,00 (protrusão +14,00 mm além da
face do nariz). O anel de fuga de 1,00/0,25/0,25 mm com a matriz continua existindo — não vem da bipartição, e é
a rota que a simulação 3D tem de fechar.

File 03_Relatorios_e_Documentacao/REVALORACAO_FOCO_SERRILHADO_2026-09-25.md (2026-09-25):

# Reavaliação com os olhos no serrilhado — 25/09/2026

Ele pediu isso: *"acho que você está viajando e prestando atenção em coisas que não deveria prestar…
reavalie tudo, calmamente, devagar, haja como uma outra persona… PRECISAMOS RESOLVER O SERRILHADO DA
MANTA, OBJETIVO PRIMORDIAL"*. Este documento é essa reavaliação. Escrito como quem chegou agora e só
aceita o que está medido em arquivo do repo. Nada de cota foi alterada; nenhuma revisão foi aberta.

**Veredito em uma linha:** o serrilhado é falta de material chegando nas pontas da fenda, e as três
matrizes que eu medi hoje **não têm nada que alimente a fenda ao longo dos 75,00 mm** — nem a copo, nem a
v30, e é por isso que refrigeração, espessura e ajuste de bancada só mascaram.

---

## 1. Onde eu estive olhando para o lado

* **Rounds 8ª e 9ª (refrigeração).** Eu gastei duas rodadas em como esfriar a matriz e o cabeçote, em foto
  de máquina parada, em manômetro, em alça de ferro. O que sobra disso: **refrigeração muda a hora em que a
  borda rasga, não a quantidade de material que chega na ponta.** Ela é paliativo e está estacionada no
  relatório `RESFRIAMENTO_MATRIZ_COPO_2026-09-25.md` — não jogada fora, mas não é o alvo.
* **Espessura como fim.** A igualização de espessura apareceu em vários textos como objetivo. Ela é
  *sintoma*. O fim é o denteado nas duas bordas.
* **A v30 como resposta.** Eu defendi a v30 por ela ser uma matriz limpa (peça única, boca rasa, sem junta).
  Limpa não é equilibrada. Ver §4.

## 2. O que está provado, medido hoje no STEP (rodo em `04_/medir_alivio_pontas.py`)

Método: varredura de ponto dentro do sólido, sem booleiana, sem malha, sem CFD. Para cada estação da fenda
(centro, ±18,75, ±30,00, ±36,60) e cada profundidade atrás da boca, o script mede a **abertura do canal**.

| o que foi medido | Copo (está na máquina) | Jonatha v30 (pacote publicado) | Gedeon CERTA (a que ele diz que dá certo) |
|---|---|---|---|
| abertura da fenda na boca, centro → ponta | 1,52 em todas | 1,52 em todas | 1,50 em todas |
| alívio/rebaixo nas pontas? | **não tem** | **não tem** | **não tem** |
| canal que alimenta a ponta, a 11 mm atrás da boca | **18,90 mm** | **1,52 mm** (a boca, sem abrir nada) | 1,52 mm (é a própria fenda) |
| comprimento do trecho paralelo (land) | **10,00 mm** | **8,50 mm** | **88,00 mm** (fenda paralela de Z 20,98 a Z 109,00; o corte começa em Z 0,17, mas até Z 20,98 ele está dentro do cone de entrada Ø75,60) |
| como a fenda é alimentada | de um furo Ø75,60 que tem de **espalhar de lado** | de um funil cônico que **fecha** nas pontas | **pelo comprimento inteiro de uma vez** (a boca da fenda fica na face de trás, dentro do bolso do cabeçote) |

As duas primeiras linhas já derrubam uma coisa que foi dita aqui com segurança demais: **não é o "recurso"
dele (alívio nas costas) que faz a Gedeon funcionar — ela não tem alívio nenhum.** Ela tem outra coisa.

## 3. A diferença que aparece quando se mede, e não quando se argumenta

A fenda de 75,00 mm tem de receber material. Duas maneiras de fazer isso:

1. **Alimentar por uma cavidade** (a copo, e a v30 com o funil): o material chega pelo eixo e tem de correr
   para os lados, 37,50 mm, por um canal que na v30 tem **1,52 mm de altura** na ponta. Cada milímetro dessa
   altura conta **³√** — com n = 0,32 do mastique, uma diferença pequena de caminho vira um déficit grande de
   material na borda. É o que a dele mede: **58–60 % de material na ponta contra 100 % no centro.**
2. **Alimentar ao longo do comprimento** (a Gedeon): a fenda é um corte que atravessa a peça, então a boca de
   entrada da fenda está exposta ao material **nos 75,00 mm de uma vez**. Não existe caminho lateral. Não
   existe ponta com menos pressão. **A fenda não tem para onde ser desequilibrada.**

E o land de 88,00 mm da Gedeon é o preço dessa escolha (e o reforço dela): com o atrito do land valendo
2,187 bar/mm, a conta do próprio repo dá **193 bar** para passar pelos mesmos 15.000 mm³/s. Ela compra
uniformidade com pressão — e é por isso que a boca dela é um corte reto de 1,5 atravessando a peça inteira: o
material entra na fenda **ao longo dos 75,00 mm de uma vez, num plano só**, no fundo do cone.

O script fecha a conta em uma linha: o desequilíbrio é uma resistência extra fixa (δR) que a entrada deixa
nas pontas. Alongar o land não muda δR; muda a **fração** que δR representa no total. Calibrando δR no que
ele mediu na copo (15,8 % com 10,00 mm de land):

| matriz | land | deficit que a mesma δR produz | pressão só no land |
|---|---:|---:|---:|
| Copo (hoje) | 10,00 mm | **14,3 %** | 22 bar |
| Jonatha v30 | 8,50 mm | **12,3 %** (e a δR dela é maior que a da copo, porque o funil fecha nas pontas) | 19 bar |
| land 31,60 mm | 31,60 mm | 4,5 % | 69 bar |
| land 52,70 mm | 52,70 mm | 2,7 % | 115 bar |
| Gedeon CERTA | 88,00 mm | **1,7 %** | 193 bar |

**Leia a tabela na vertical, não na horizontal.** Não existe linha "land curto e manta lisa" alimentando por
cavidade. As opções são duas, e só essas: **alimentar a fenda ao longo do comprimento** (sem pagar pressão) ou
**comprar land** (pagando de 3 a 9× a pressão de hoje).

## 4. O que isso diz da v30, sem defesa e sem ataque

* Ela tem razão quanto ao que melhora: peça única (sem junta, sem rebarba de junta), boca rasa (não enterrada
  14,30 mm como a copo), lábio mais robusto.
* Ela está errada no que ele pediu. O land foi de 10,00 (copo) para **8,50 mm**, e o funil cônico deixa a
  ponta com **1,52 mm** de canal — ou seja, na direção do serrilhado ela anda para trás, não para frente.
  Isso é medida, não opinião, e é a versão numérica do "o projeto de vocês não vai resolver a questão do
  fluxo" que ele disse em áudio. Eu li aquilo como opinião de matrizaria; é previsão correta.
* A decisão sobre a v30 continua valendo para usinagem de *outra* coisa (a peça única como forma); ela não é
  resposta para o serrilhado e não deve ser defendida como se fosse.

## 5. O que fazer, na ordem, com o custo de cada passo

1. **Medir o perfil da manta da Gedeon nos mesmos 5 pontos** (10 minutos, zero usinagem, zero risco). Se a
   Gedeon der ~1,50 nos cinco pontos com um land de 88,00 mm alimentando pelo comprimento, o princípio está
   provado **na linha dele**, com a extrusora dele. É o único experimento que decide entre as duas opções da
   tabela sem eu precisar convencer ninguém de nada.
2. **Girar a matriz 180° e remedir** (grátis, já estava pendente): se a assimetria +25 % trocar de lado, é
   assento/montagem; se ficar no mesmo lado da máquina, é a máquina, e nenhuma matriz resolve isso.
3. **Medir com régua o passo das ondinhas do centro** (grátis, 5 minutos) e comparar com o passo da rosca:
   separa pulsação da rosca de defeito de matriz. Sem isso, tudo que a matrizaria fizer vai ser avaliado com o
   ruído da extrusora dentro da amostra.
4. **Rev. 31 — o desenho muda de alvo.** Esquecer "gotas + sorriso + chanfro" como *a* solução; isso é ajuste
   fino de uma matriz que já nasce desequilibrada. O alvo passa a ser um destes dois, e só um:
   * **A. Fenda alimentada ao longo do comprimento** — a boca de entrada da fenda aberta para o bolso, como na
     Gedeon (corte atravessado: a fenda aberta até a face de trás, onde o bolso do cabeçote já enche de
     material), ou um rasgo raso correndo atrás do land nos 75,00 mm, mais alto nas pontas.
     Não paga pressão; paga usinagem (EDM atravessado, e a matrizaria dele já fez isso uma vez).
   * **B. Land comprido** — 30 a 35 mm de land paralelo em vez de 8,50, pagando ~69 bar só no land (a Gedeon
     paga 193 com 88,00 mm, e é a prova de que a extrusora dele aguenta mais do que hoje). Cabe no
     corpo de 80,70? Sim: sobram 45 mm para a cavidade. Mas **depende de quanto de pressão essa extrusora
     entrega nessa rosca** — número que eu não tenho e não vou inventar.
   O chanfro 1,50 → 0,50 que já estava na proposta continua sendo um passo *na direção certa* (land 8,50 →
   9,50, +4,8 % de ΔP), mas ele é de 12 % para 11 % — é cosmético diante do problema.
5. **Só depois disso** volta a conversa de refrigeração (§8 do relatório estacionado), porque ela passa a ser
   *set-point* de uma matriz que finally entrega material igual nas pontas, e não band-aid de uma que não
   entrega.

## 6. O que eu preciso dele, e são três números (nenhum é difícil)

1. **Perfil da manta da Gedeon, 5 pontos** (1,5 / 18,75 / centro / 18,75 / 1,5). É a peça inteira do raciocínio.
2. **Quanto de pressão a extrusora dele entrega**, manômetro da adjunta em produção, em bar. Sem isso, a
   opção B não pode nem ser cogitada — e eu não volto a propor nada que dependa dela.
3. O que ficou sem resposta das rodadas anteriores: **a área real da amostra que ele pesou** (para eu devolver
   a densidade medida do mastique dele) e **o texto do item 2** que veio vazio duas vezes.

---

*Registro de procedimento, para ele poder conferir: nenhuma linha deste arquivo usa número de memória. As
aberturas, os comprimentos de land e a fenda atravessada da Gedeon saíram de `04_Dados_SSOT_e_Scripts/medir_alivio_pontas.py`
rodado hoje contra os STEP do repo; o gradiente 2,187 bar/mm, o n = 0,32 e a vazão 15.000 mm³/s são do
método 1D do projeto (PRP-0002, SSOT). O perfil de espessura (1,5 / 2,5 / 2,5 / 2,0 / 1,5 e a 1ª medição) é
medida dele na linha, com o erro que ele mesmo declarou.*

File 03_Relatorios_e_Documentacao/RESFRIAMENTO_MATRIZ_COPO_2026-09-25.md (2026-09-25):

# A matriz copo dentro do cabeçote — o que dá para resfriar, e onde

**2026-09-25, 9ª rodada.** Pediu: *olhe como a matriz copo fica no cabeçote e pense no resfriamento.*
Alvo dele continua sendo o **serrilhado nas pontas** (rodada 8ª). Espessura não é o problema dele, e este
documento não trata de espessura.

**De onde saem os números:** todos os mm abaixo foram medidos nesta rodada, com `cadquery`, no arquivo
`06_CAD_Cabecote_EX-030/STEP/Cabecote_EX-030_com_Matriz_Copo.step` (montagem real: cabeçote + matriz copo,
cada um no seu sólido, sem booleano) e nos STEP das outras matrizes montadas no mesmo cabeçote. Distância de
peça a peça é `BRepExtrema`. Volume é `GProp`. A conta de calor usa o land medido no STEP e a vazão
Q = 15.000 mm³/s, K = 18.500, n = 0,32 do `04_Dados_SSOT_e_Scripts/verify_legacy_dies.py`, com a lei do
gradiente 2,187 bar/mm do `05_Interface_Auditoria/propostas/PRP-0002`. Densidade do aço 7,85e-6 kg/mm³,
cp do aço 486 J/kg·K, cp do mastique 2 J/g·K, ρ do mastique 1,25e-3 g/mm³
(`04_Dados_SSOT_e_Scripts/masti_epdm_reologia.py:59`), k do aço 45 W/m·K, k da borracha 0,25 W/m·K.

**Para conferir sem depender da minha palavra:** `python3 04_Dados_SSOT_e_Scripts/verificar_resfriamento_copo_2026_09_25.py`
re-mede os STEP e re-faz cada conta deste documento, comparando com o valor escrito. Estado na rodada:
**54 conformes, 0 divergentes**.

---

## 1. O que é a matriz copo (medido)

| o quê | medido |
|---|---|
| corpo | Ø93,00 × 80,70 mm (volume 224.289,0 mm³ = **1,761 kg**) |
| o "copo" | furo **Ø75,60 × 70,70 mm** de fundo, entrando pela **traseira** |
| a fenda | 75,00 × 1,500, R 0,75, atravessando o fundo do copo: land = **10,00 mm** (Z 70,70 → 80,70) |
| boca | **sem chanfro** e **sem funil**: o fundo do copo é um degrau reto de 90° contra a fenda |
| casca total | **55.129,7 mm²**, face por face: banda Ø93 **20.422,6** (37,0 %) · furo do copo Ø75,60 **16.791,6** (30,5 %) · face frontal **6.179,2** (11,2 %) · fundo do copo **4.376,8** (7,9 %) · estágio Ø89,5 **3.036,7** (5,5 %) · face traseira **2.304,1** (4,2 %) · paredes do land **1.517,1** (2,8 %) · ombro **501,7** (0,9 %) |
| onde ela toca massa | furo + fundo + face frontal + land = **28.864,7 mm² = 52,4 %** da casca. Os outros 47,6 % estão em vão de 0,10–1,00 mm. **Nada dela toca o ar.** |

Referencial: **Z = 0** é o plano mais traseiro do cabeçote; a **face do nariz** do cabeçote (por onde a manta
sai para o ar) está em **Z = 95,00**.

## 2. Como ela fica sentada — face a face, enterrada

| parte da matriz | onde cai no cabeçote | folga medida (BRepExtrema) |
|---|---|---|
| banda Ø93,00, Z 0,00 → 69,90 | bolso Ø95,00 (Z 0,00 → 70,00) | **1,00 mm** radial — ar parado; e é a banda que o collete aperta |
| ombro (anel Ø89,5→Ø93) em Z 69,90 | degrau em Z 70,00 | **0,10 mm** axial; anel de 501,7 mm², contato real 431,2 mm² quando a pressão fecha |
| estágio Ø89,50, Z 69,90 → 80,70 | furo Ø90,00 (Z 70,00 → 81,00) | **0,25 mm** |
| **face de saída**, Z 80,70 (anel de 6.179,2 mm²) | o metal mais próximo é a parede do furo Ø90,00; o plano do degrau está 0,30 mm à frente | **0,25 mm** radial / **0,30 mm** axial |
| face traseira, Z 0,00 (anel de 2.304,1 mm²) | rasa com a traseira do cabeçote → no canal de massa | — |

As três consequências, todas medidas:

1. **A boca da matriz está 14,30 mm para dentro do cabeçote** (80,70 contra 95,00). À frente dela há
   **70.371,7 mm³** de furo Ø80,00 × 14,00 mm, e esse vão fica **cheio de massa** — a manta nasce dentro de
   um túnel do cabeçote e só vê ar depois de 14,30 mm.
2. **Nenhuma parte da matriz vê o ar.** Os 55.129,7 mm² da casca estão todos ou molhados de massa (52,4 %) ou
   num vão de 0,10–1,00 mm (47,6 %). A banda, que é 37,0 % da casca, está no vão de 1,00 mm de ar **e** é a
   banda de aperto do collete: não dá para encostar nada ali.
3. **A copo não pode ser feita protruir.** Para a boca sair do túnel faltariam 1,50 mm de raio: a banda
   Ø93,00 não passa do degrau Ø90,00, e a folga axial de encosto no degrau é de 0,10 mm (0,091 mm na varredura de 0,20 mm do `medir_perfis_matrizes_x_cabecote.py`).
   *Comparação medida nas outras montagens do mesmo cabeçote:*

| matriz | comprimento | face de saída | boca em relação à face do nariz |
|---|---|---|---|
| **copo (a que está na máquina)** | 80,70 | Z 80,70 | **14,30 mm para dentro** |
| JONATHA **v30** | 95,00 | Z 95,00 | **rasa (0,00)** — a boca fica no plano da face, alcançável |
| JONATHA v29 / v27 | 109,00 | Z 109,00 | **14,00 mm para fora** — boca livre, mas o túnel não é resfriado |

## 3. Por que ela "enche de calor" mais rápido que a v30

- A copo tem **855,7 J/K** de capacidade térmica (1,761 kg × 486). A v30 tem 1.673 J/K: **o dobro de aço
  para esfriar**. Ou seja, a copo esquenta o dobro mais rápido com o mesmo watt.
- Dentro do copo ficam **318.480,7 mm³ de massa** (medido no `Matriz1_Original_Copo_Canal_Fluxo.step`):
  **398 g** de borracha, outros **796 J/K** a 90 °C, trocados a cada **21,2 s** (V/Q). Essa massa dentro do copo
  toca o furo e o fundo: **21.168,4 mm² = 38,4 %** da casca da matriz. O copo é banho-maria por dentro, e por
  fora o vão de 1,00 mm de ar não deixa sair nada.
- Calor que a fenda gera: ΔP_land = 2,187 bar/mm × 10,00 = **21,87 bar** → 21,87e5 Pa × 15,0e-6 m³/s =
  **32,8 W**. O teto da rodada 8ª (simulação do pacote, 203,6 bar) foi **305 W**.
- Com esse calor preso: **33 W sobem o lábio 20 °C em 8,7 min**; **300 W em 0,95 min**. Isso é o sintoma dele:
  sai boa no começo, e "aos poucos, quando acelera a produção, vai enchendo de calor".
- **Leia a linha de cima como teto, não como previsão** (corrigido nesta rodada, §11.1): ela vale só se o calor
  não tiver por onde sair. Tem. Com a massa entrando 0,9 °C mais fria que a matriz, a própria manta leva os 32,8 W
  embora (§6-D). Então o "enchendo de calor" não é o canal gerando mais do que o canal exporta — é o **bloco do
  cabeçote ensopando de calor vindo de trás**, que é o que a §11 mede agora.

## 4. Os caminhos que o calor tem — e o gargalo de verdade

Resistência térmica = espessura ÷ (k × área). Folgas medidas na tabela 2:

| caminho da boca da matriz para fora | R (K/W) | 300 W custam |
|---|---|---|
| filme de **massa** de 0,30 mm na face frontal (6.179,2 mm²) | **0,194** | 58 K |
| o mesmo vão de 0,30 mm cheio de **ar** | 1,867 | 560 K |
| filme de 0,25 mm no estágio Ø89,50 (3.036,7 mm²) | 0,329 | 99 K |
| filme de 1,00 mm de ar na banda do collete (20.422,6 mm²) | 1,883 | 565 K |
| 18,50 mm de aço do nariz até a banda Ø130 (17.153,1 mm²) | 0,024 | 7 K |
| água com h = 2.000 W/m²·K num colar de 28,00 mm (11.435,4 mm²) | 0,044 | 13 K |

**Ler isso em português:** o caminho curto existe. A face da matriz está a **0,25–0,30 mm** do aço do
cabeçote, e o vão de 1,00 mm da banda (onde o collete aperta) é o que não vale nada. Como a matriz trabalha a
20–200 bar, esse vão de 0,30 mm está cheio de massa, não de ar — e é por esse filme que o aquecimento entra
**e** por ele que dá para o calor sair.

## 5. A conclusão da rodada: com a copo, o resfriamento é no cabeçote — na faixa do degrau

Isso é a decisão que ele já tinha tomado (refrigeração no `06_CAD_Cabecote_EX-030`, não na matriz), e agora
tem número:

- O corpo do cabeçote tem uma **banda lisa Ø130,00 de Z 53,00 a 95,00** (42,00 mm, 17.153,1 mm² de aço),
  a **18,50 mm** da banda da matriz. É a única superfície de aço grande, limpa e alcançável do conjunto.
- Furos no corpo do cabeçote, medidos na montagem: os 6 furos Ø16,5 da junta passam a **35,25 mm** da matriz
  e ficam em Z 3,00–43,00; o único furo transversal na região útil é o **M12 do pushador, em Z 22,98** —
  ambos **fora** da faixa 53–95. Então a banda está livre para receber um colar.
- **Não fure o cabeçote para passar água:** ele é SAE8620 cementado 0,4–0,6 mm e temperado a 52–55 HRC
  (`04_Dados_SSOT_e_Scripts/cabecote_ex030.json`). Furo/rosca nessa carepa é trabalho de EDM, não de furadeira.
- **Capacidade:** se a faixa 53–81 ficar 40 °C mais fria que a matriz, os filmes de 0,30 e 0,25 mm puxam
  40/0,194 + 40/0,329 ≈ **330 W**. Isso é mais que os 33 W do land e da mesma ordem do teto de 305 W.
- **Quanta água:** 300 W = **+4,3 °C** de elevação em **1 L/min** (0,2 L/min = 21,5 °C; 3 L/min = 1,4 °C).
  Uma torneira de tanque chega. Chiller não é necessário.
- **Limite honesto:** o gargalo é o filme de 0,30 mm, não a água. Ele leva ~150 W com 30 °C de diferença.
  Se o vão de 0,30 mm estiver com ar (matriz parada, ou massa que não entra no vão), a conta cai 10×.

## 6. O que fazer, do de graça para o que custa um dia

**A. Pano encharcado + gotejador na banda Ø130 (Z 53 → 81).** Custo zero, teste para hoje. Uma faixa de
pano/algodão molhado dada de volta a cada tanda, ou um pano passado por um fio gotejando. h de evaporação em
pano molhado é da ordem de 100–300 W/m²·K sobre os 11.435,4 mm² da faixa → **0,3 a 0,9 K/W**. Traduzindo: o
pano leva os **33 W do land com 10 a 30 °C de diferença** — que é o que se consegue a céu aberto. Os 300 W do
pior caso não saem por pano, só por água. **Regra do teste:** cronometre o tempo até o primeiro dente de serra,
com e sem o pano, na mesma velocidade. Se o tempo dobrar, é térmico.

**B. Faca de ar na manta, 3–5 cm depois da FACE DO NARIZ — não na boca.** Com a copo a boca está a 14,30 mm
para dentro do túnel, então nada de tentar soprar na matriz: o ar tem de pegar a manta **depois** que ela sai
do Z = 95,00. Fenda de 0,5–1,0 mm nos 75 mm, ar a 0,3–0,5 bar. Isso resfria a pele **e** segura a borda
contra o puxamento do centro — é o item que mexe nos dois lados do serrilhado.

**C. Colar d'água partido na banda Ø130, faixa Z 53 → 81 (28,00 mm).** Duas conchas com canal de 3 mm e
O-ring, abraçadeira de corona. Não fura o cabeçote, não encosta na matriz, não pega o pushador (Z 22,98) nem
os furos da junta (Z 3–43). **Por que parar em Z 81,00:** Z 81–95 é o nariz, o túnel por onde a manta sai.
Resfriar o túnel é o caminho mais rápido para a massa congelar na parede do furo Ø80 e virar incrustração —
que é exatamente o motivo pelo qual o projeto evita boca dentro do cabeçote. Resfrie **atrás** do degrau e
deixe os 14 mm do nariz do jeito que estão. Usinagem: meia hora de torno na matrizaria, sem EDM.

**D. Mastique chegando mais frio (a alavanca mais forte, e é de graça).** A vazão mássica é 15.000 × 1,25e-3
= **18,75 g/s** → cada **1 °C** a menos na massa que entra no copo leva embora **37,5 W**. Ou seja: para
compensar os 33 W do land bastaria a massa entrar **0,9 °C** mais fria. O preço é justo saber: sobe a pressão
(já alta) e a casca solda pior no R 0,75, que é onde a manta arrebenta.

**E. O que não fazer, com o motivo medido:**
- **furo de água dentro da copo: a conta nem abre.** Entre o furo do copo (Ø75,60 → raio 37,80) e o corpo
  (Ø93,00 → raio 46,50) há **8,70 mm** de aço. Um furo Ø4,00 com a parede mínima de **4,00 mm** exigiria o
  centro entre 37,80 + 6,00 = **43,80** e 46,50 − 6,00 = **40,50** mm de raio. Faixa vazia: **não existe
  posição** para furo de água na copo. (Na v30, com corpo Ø94,00, a janela existe e é de 1,2 mm — rodada 8ª.)
  E na altura do land seria pior ainda: da fenda até o Ø89,50 há **44,00 mm** de aço, longe da boca onde o
  calor nasce.
- **usar o furo M12 (Z 22,98) como entrada de ar/água:** ele dá no bolso onde o collete aperta, não na
  matriz; e é pelo mesmo furo que a matriz é expulsa (pushador EX-032).
- **espaçador para a copo protruir:** bloqueado pela geometria — faltam 1,50 mm de raio (item 2.3).

## 7. Como controlar, sem ver a boca

O termômetro de infravermelho **não alcança a boca** na copo: ela está enterrada 14,30 mm dentro de um furo.
O ponto alcançável mais quente e mais ligado a ela é a **face do nariz do cabeçote (Z 95,00, anel
Ø80→Ø130, 8.246,7 mm² de aço, a 14,30 mm da boca e ligada a ela pelo filme de 0,30 mm)**. Então:

1. Rode e meça `T_limiar` na **face do nariz** (não na matriz) no instante do primeiro dente de serra.
2. Uma vez só, pare uma tanda, espere esfriar o suficiente para abrir e meça a boca com termopar de ponteira;
   isso dá o offset boca↔face, que é constante enquanto a folga for a mesma.
3. Regra operacional: **segurar a face em `T_limiar − 10 °C`** com o pano ou com o colar, ligando e desligando.
4. Confirmação do mecanismo: tempo até o primeiro dente em 100 / 80 / 60 % da velocidade. Se escalar
   ~1× / 2,0× / 4,6× (o escalonamento 1/v³ da rodada 8ª), é aquecimento viscoso mandando, e o colar resolve.
   Se **não** escalar assim — se depender mais do tempo de máquina ligada do que da velocidade — é o bloco
   ensopando (§11.1), e aí o remédio não é esfregar menos, é **segurar a temperatura do cabeçote**.
5. Não congele demais: o lábio frio sobe a pressão e impede a casca de soldar no R 0,75 — não água gelada
   contínua. **O "10–25 °C abaixo da cabeça de aquecimento" que eu tinha escrito aqui não tem o que referenciar:
   ele confirmou que o cabeçote não tem abraçadeira (§11).** A referência passa a ser **o °C da adjunta que o
   mostrador de trás mede** — que não é a temperatura da matriz, mas é o teto de onde ela vem.

## 8. O que isto tem a ver com o serrilhado (e o que não tem)

- **Tem:** borda serrilhada é a ponta sendo arrancada pelo centro. Uma casca fria e endurecida na saída segura
  a ponta (itens B e C). E o túnel de 14,30 mm da copo é onde a borda ainda está apoiada — resfriar atrás do
  degrau endurece essa região sem incrustrar o túnel.
- **Não tem:** resfriar não tira a tração da borda, só ganha tempo. O par continua sendo a refrigeração +
  **gotas nos extremos da fenda + arco do sorriso (flecha 1,50 mm) com chanfro 0,50×45°**, que é a rev. 31 /
  PRP-0007 e depende de ele dizer sim. Detalhe medido que joga a favor: **a copo não tem chanfro nenhum** na
  boca e o land dela é de 10,00 mm — mais agressivo que os 8,50 mm + chanfro 1,50×45 da v30.

## 9. Pendências desta rodada

*Atualizadas depois das fotos dele (§10): das quatro perguntas que eu tinha aberto, três foram respondidas pela
própria máquina — a banda está **livre** (item 1), **não existe água** no cabeçote (item 3, e a linha de água
passa a ser serviço novo, pequeno) e **não existe puxador** (o que eu tinha lido como puxador é a estação de
papel siliconado; a manta sai da matriz e entra na esteira). E o `T_limiar` **precisa** de instrumento comprado:
o mostrador de 0-150 °C das fotos está no corpo de trás, não no cabeçote (§10.1.3). Sobram as de baixo.*

1. ~~O cabeçote é aquecido hoje?~~ **Respondido por ele: "NÃO TEM".** A pergunta deixou de ser pendência e virou
   o §11 inteiro: sem aquecedor, sem instrumento e sem isolamento, o cabeçote é 12,327 kg subindo livremente com
   **0,254 W/K** de perda para o ar, e isso bate com a escala de tempo do defeito (§11.1). A ação que sobra dele
   é o teste de seis leituras da §11.3.
2. ~~O cano curto na frente da faixa~~ — **fechado duas vezes, e a segunda por ele.** Primeiro pelo desenho: o
   EX-030 não tem camisa d'água nem dreno (§10.3.1). Depois pela resposta dele: **"alça de ferro"**. Não muda
   nada no plano da refrigeração — muda um detalhe da abraçadeira, que é o recorte por onde a alça passa.
3. **O rolo de papel siliconado fica encostado em parte quente?** Afastá-lo é de graça e é a única coisa na linha
   que hoje toca a face da manta logo depois da boca.
4. Continuam valendo da 8ª: `T_limiar` com o teste das três velocidades (100/80/60 %), o giro de 180° da matriz
   antes de cortar, e a área real da amostra (para eu devolver a densidade medida).

---

## 10. O que as fotos da máquina respondem (repo `ity1300-wq/ACESS`, 25/09 14:08)

Ele mandou ver o repo `ACESS` — seis fotos e um vídeo da extrusora. Lidas uma a uma, com as sete mídias
baixadas e conferidas por sha256. **Procedência** (o arquivo fica no repo dele; a cópia local está em
`/home/user/uploads/ACESS_2026-09-25/`, que não é versionada):

| arquivo | bytes | sha256 (16 primeiros) |
|---|---|---|
| `WhatsApp Image 2026-09-25 at 14.08.52.jpeg` | 123.600 | `d79c7707ba13acae` |
| `WhatsApp Image 2026-09-25 at 14.08.53.jpeg` | 115.007 | `aa009a98e66acbc6` |
| `WhatsApp Image 2026-09-25 at 14.08.531.jpeg` | 125.383 | `7bfb59b74a92abba` |
| `WhatsApp Image 2026-09-25 at 14.08.54.jpeg` | 78.476 | `80d7641f777f9977` |
| `WhatsApp Image 2026-09-25 at 14.08.542.jpeg` | 106.625 | `09508b24f2b7b8e0` |
| `WhatsApp Image 2026-09-25 at 5.jpeg` | 67.229 | `e8116319be8f0181` |
| `WhatsApp Video 2026-09-25 at 14.08.52.mp4` | 7.731.854 | `ee4a17a249b9efb5` |

**Regra que eu mesmo me dei depois do erro do disco de corte:** foto responde *o que está onde*; foto não
responde *como o processo roda*. Tudo abaixo está escrito como "aparece na foto", e onde há dedução ela está
marcada como hipótese. Nenhuma mídia foi commitada (o repo é público e as fotos são da linha dele). Como os
objetos foram localizados: sem segmentação por cor e sem "pixel vira cota" — a foto 14.08.53 foi reimpressa com
**grade de 100 px** e relida, depois marcada (`grade_53.png` e `anotado_53.png`, na mesma pasta de uploads); foi
isso que tirou o mostrador de cima do cabeçote. O vídeo (848 × 478 px, 15 quadros extraídos) só sustenta
"existe / não existe". O áudio não foi transcrito — não há transcritor neste ambiente —, então nenhuma fala foi
usada aqui.

### 10.1 O que aparece, e o que isso fecha

1. **A boca enterrada está confirmada.** Na ponta do cabeçote aparece uma **face plana de aço sem tinta com um
   furo redondo**, e é por esse furo que a chapa passa. No vídeo (~22 s) há uma tira cinza atravessada ali, e
   **ele respondeu o que é: resquício de manta velha**, com a máquina parada — não é produto em processo e não
   vale como evidência. **Nenhuma boca de matriz aparece fora do cabeçote.** É exatamente o que a medição do CAD deu: face da matriz em Z 80,70 contra a face
   do nariz em Z 95,00, e um túnel Ø80,00 × 14,00 mm na frente.
2. **A faixa onde eu propus o colar d'água está livre.** A faixa de aço sem tinta na ponta (o corpo do
   cabeçote) está **sem abraçadeira de aquecimento e sem manta térmica**; o que há em volta é o garfo azul onde
   o papel é aplicado, à frente da matriz — **a distância não dá para medir nessas fotos**, então quem fabricar o
   colar mede na máquina. Então o colar pode ser abraçado ali, sem tirar nada de lugar. **Atenção a
   um item só:** na borda dessa faixa (fotos 14.08.53 e 14.08.531) aparece uma peça curta de Ø ~25 mm apontando
   para baixo, e eu perguntei o que era. **Resposta dele: é alça de ferro.** Não é tubo, não tem furo, não drena
   nada — é ponto de pega para manusear o cabeçote. Para o colar isso é detalhe de projeto, não obstáculo: a
   abraçadeira precisa de um **recorte para passar a alça** (ou terminar antes dela), e o pano encharcado (opção
   A) pode continuar passando por cima sem problema nenhum.
3. **Aqui eu errei, e ele corrigiu: os manômetros ficam longe do cabeçote.** Na primeira versão desta §10 escrevi
   que o mostrador de 0 a 150 °C estava "no corpo, logo atrás do flange da matriz" e que ele servia de régua para
   o teste da §7. Remedi a foto 14.08.53 com grade de coordenadas por cima da imagem: o mostrador está no **corpo
   azul de trás**, depois do flange aparafusado — é a adjunta/cilindro, **não o cabeçote**. Ele não mede a matriz,
   e nas fotos marca ~25-30 °C, que é temperatura de sala com a máquina parada.
   * O que sobe daí, e é a coisa mais acionável desta rodada: no que aparece nas cinco fotos e no vídeo, o
     **cabeçote não tem instrumento, não tem abraçadeira de aquecimento e não tem isolamento** — a faixa dele está
     de aço nu. Se na máquina quente for igual, então hoje **a temperatura da matriz não é medida nem controlada
     por ninguém**: ela é o resultado da condução que vem da adjunta de trás, do atrito na fenda e do que o ar
     leva. É a **P3 da `03_/TRIAGEM_DE_PROBLEMAS_DAS_MATRIZES.md`** ("matriz sem controle térmico") aberta na
     máquina dele, e o "sai boa no começo, depois piora" é a assinatura disso.
   * **Consequência para o plano:** o infravermelho **volta a ser necessário** (ou termopar de contato/ponteira
     magnética encostado na faixa sem tinta), porque não há nada instalado que responda "a que °C está a matriz
     agora". É o instrumento mais barato do projeto inteiro, e é ele que fecha o teste da §7.
4. **Não há água no cabeçote.** As mangueiras pretas que aparecem em cima dos corpos azuis entram por **cupom
   de aperto tipo prensa-cabo (conduíte)**, não por conexão de água; não há torneira, mangueira de água nem
   dreno no conjunto da matriz. Ou seja: se a opção C (colar d'água) for escolhida, a linha de água é trabalho
   novo — mas pequeno: 1 L/min, §5.
5. **O que eu li como puxador é a estação de papel — e a manta vai para a esteira.** Correção dada por ele nesta
   rodada: a primeira versão desta §10 dizia "existe puxador", e estava errado. O que aparece: um **par de rolos de aço nus** num garfo azul com fuso e mola, e uma **bobina de papel
   siliconado** guiada por roletes de nylon. **A manta sai da matriz e entra na esteira**, com o papel aplicado
   sobre ela. O que muda:
   * **não há puxador fechando ciclo de estiramento.** Então volta a valer o que estava na 7ª: o inchaço acontece
     livre depois da boca. O teto de 2,20 mm que usei para a flecha do sorriso — justificado por "sem puxador" —
     **continha**, e eu retiro a frase que escrevi na primeira versão desta seção dizendo que ele caía.
   * papel siliconado é **papel de liberação**, não tecido colado: ele cobre uma face da manta logo na saída. É
     um contato de resfriamento que já existe na linha, de graça. **Não li nas fotos a que temperatura papel e
     rolos chegam** e não vou deduzir isso de pixel — mas é regulável: ver a pergunta 4 da §10.3.
6. **O que controla a rosca é inversor.** O painel tem keypad WEG com "ajuste de velocidade", botão de esteira e
   alerta; o outro painel (caixa bege na plataforma) tem chave rotativa e um controlador digital — presumo ser
   o de temperatura. Isso importa para o teste da §7.4: baixar a velocidade em 80/60 % é só mexer no keypad, e
   o tempo até o dente pode ser cronometrado com o painel na mão.

### 10.2 Correção que as fotos fazem no meu plano

* **Item da §7 que NÃO muda — e por que eu achei que mudava:** eu escrevi nesta §10 que o IR era dispensável
  porque "o mostrador do corpo serve". **Não serve: ele me corrigiu, os manômetros ficam longe do cabeçote.**
  Conferido na foto com uma grade de pixels por cima — o mostrador de 0-150 °C está no corpo azul de trás, depois
  do flange aparafusado, e mede a adjunta. Então a §7 continua como foi escrita na 8ª rodada: **IR (ou termopar de
  ponteira) na face do nariz do cabeçote**, que é o ponto mais próximo da boca que se alcança. O que muda a favor
  dele é outro: se hoje o cabeçote não tem instrumento nem aquecedor, o teste das três velocidades pode ser rodado
  **sem mexer em nada do processo**, e o `T_limiar` que sair dali é o primeiro número de temperatura de matriz que
  esta máquina já deu.
* **Item da §6 que ganha detalhe:** o colar (opção C) tem que **dar um recorte na alça de ferro** (o item de
  Ø ~25 mm na frente da faixa — ele confirmou que é alça, não tubo) **ou terminar antes dela**, e **não pode
  estorvar o garfo onde o papel é aplicado**. Faixa útil provável: da face do flange azul para trás, na parte lisa
  do corpo. A alça **não** atrapalha a opção A (pano/gotejador), que é só envolver e não precisa fechar.
* **Hipótese que eu levantei e ele derrubou (registrada para ninguém ressuscitar):** eu escrevi que a tira do
  vídeo encostava no fio do furo e que, se a manta corresse descentrada, a quina raspava no furo do nariz — o que
  daria ao serrilhado uma causa mecânica além da térmica. **Resposta dele: "ignore isso, é resquício de manta
  velha, é filme papel siliconado, a manta sai da matriz e entra na esteira".** A peça do vídeo não é produto em
  processo. A folga medida no CAD (2,50 mm por lado) continua sem contra-evidência, e o diagnóstico da 8ª
  permanece com as duas causas dele: tração na borda e saturação térmica. É a segunda vez nesta conversa que
  pixel de mídia da máquina vira afirmação de processo — a regra fica: **mídia da máquina parada não prova nada
  sobre o que acontece na saída.**

### 10.3 As perguntas desta §10: duas abertas, duas fechadas no caminho

1. ~~O cano curto de Ø ~25 é dreno de camisa?~~ **Fechado pelo desenho, não pela foto.** O
   `04_Dados_SSOT_e_Scripts/cabecote_ex030.json`, lido do DWG 030-032, dá no cabeçote **quatro furos coaxiais**
   (nariz Ø80,00 em d 0-14 · intermediário Ø90,00 em d 14-25 · bolso Ø95,00 em d 25-95 · piloto Ø105,00 em
   d 92-95) e **um único furo transversal**: o roscado **M12 do bolso** (Ø10,50 de broca, centro a 72,02 mm da
   face do nariz), pelo qual o pushador EX-032 expulsa a matriz. **Não há camisa d'água, dreno ou respiro no
   EX-030** — a palavra "água" não aparece uma vez no arquivo de medição do cabeçote. Então a refrigeração **não
   está escondida na máquina esperando um mangueira**: ela tem de ser criada, e o colar da §6-C (abraçado, sem
   furar nada) continua o caminho mais curto até isso.
   *E ele respondeu o que é a peça: **alça de ferro** de manuseio — sem furo, sem função no processo. Fecha a
   pergunta, e o único efeito prático é o recorte na abraçadeira (§10.2).*
2. ~~O cabeçote é aquecido hoje?~~ **Fechada por ele: "NÃO TEM".** Foi a resposta que abriu a §11: o cabeçote não
   tem abraçadeira, não tem termopar e está sem isolamento — a perda dele para o ar é 0,254 W/K e é só isso que
   limita a subida.
3. ~~O branco da bobina é tecido laminado ou filme de transporte?~~ **Respondido por ele: papel siliconado, e a
   manta sai da matriz e entra na esteira.**
4. Uma nova, e é a única pergunta de foto que ainda vale: **o rolo de papel siliconado fica encostado em alguma
   parte quente da máquina?** Se ficar, o papel chega quente e a face da manta que ele cobre não esfria nada na
   saída — e afastar o rolo é de graça.

---

## 11. "Não tem abraçadeira" — o que a resposta dele muda, com o cabeçote re-medido agora

Ele respondeu a pergunta da §9.1: **o cabeçote não tem abraçadeira de aquecimento.** Nem termopar, nem
isolamento — a faixa está de aço nu, como já aparecia nas fotos. Isso não é um detalhe da máquina: é o motivo
pelo qual o defeito tem hora. Números abaixo cortados agora, no STEP da montagem
(`06_CAD_Cabecote_EX-030/STEP/Cabecote_EX-030_com_Matriz_Copo.step`), fatiando o sólido do cabeçote entre os
planos Z indicados (Z = 0 no plano traseiro, face do nariz em Z 95,00).

### 11.1 O cabeçote é um radiador pequeno, encostado numa adjunta quente, sem ninguém olhando

| o que | valor medido |
|---|---|
| metal solto da faixa livre (Z 53→95) | 296.625,3 mm³ = **2,329 kg**, C = **1.131,7 J/K** |
| nariz sozinho (Z 81→95) | 115.453,5 mm³ = 0,906 kg, C = 440,5 J/K |
| cabeçote inteiro | 1.570.339,5 mm³ = **12,327 kg**, C = **5.991,0 J/K** |
| área exposta (faixa Ø130 × 42,00 + anel da face Ø80→Ø130) | **25.399,8 mm²** = 0,0254 m² |
| perda só para o ar, h ≈ 10 W/m²K | **0,254 W por 1 K** (com radiação, h ≈ 15: 0,381 W/K) |
| para jogar fora os 32,8 W do land assim | a faixa teria de estar **129 K acima da sala** |

**Conclusão 1 — a 33 W, o atrito não é o disparador do "com o tempo piora".** A conta honesta é por kg de
produto, não por bloco: 32,8 W ÷ 18,75 g/s = **1,75 J/g**, e com cp = 2,0 J/g·K isso é a manta saindo
**0,9 °C** mais quente do que entrou. Não é preciso a matriz acumular nada para esse calor sair — ele vai embora
no produto. O "+20 °C em 8,7 min" da §3 é teto adiabático (hipótese de nada saindo), não previsão; rebaixado lá.
* **E para não trocar um erro por outro:** se o consumo real de pressão for o da simulação do pacote
  (203,6 bar ⇒ **305 W**, 9,3× os 32,8 W), o quadro muda de lado — a manta subiria **8,1 °C** e o caminho de
  volta pelo filme de 0,30 mm exigiria **59 K** entre a matriz e a face do nariz, que é uma coisa que a
  refrigeração nenhuma segura. É por isso que o teste de §7.4 (tempo até o dente em 100 / 80 / 60 %) não é
  decoração: 1/v³ é a assinatura do atrito mandando; escalonamento mais lento é a assinatura do bloco ensopando.

**Conclusão 2 — sobra uma explicação, e ela bate com a escala de tempo dele.** O cabeçote está recebendo calor
de trás (junta do flange Ø220 e contato com a adjunta aquecida) e a única coisa que ele tem para perder é
**0,254 W/K de ar**. A constante de tempo dessa faixa é 1.131,7 ÷ 0,254 = **4.455 s = 74 min**. Comparação que
decide: o pior caso do atrito na matriz é 8,7 min; o bloco perdendo só para o ar é 74 min — **8× mais lento**, e
é a ordem de grandeza que ele descreve ("depois de um tempo enche de calor"). Sem aquecedor, sem instrumento e
sem isolamento, **ninguém vê isso acontecer e nada limita**: é um corpo de 12,3 kg subindo livremente durante
meia jornada, e a matriz está enterrada nele.

**Por que esfregar pano no nariz funciona rápido, medido:** a matriz está ligada ao nariz por um filme de massa
de 0,30 mm, R = **0,194 K/W** (§4). Segurar a **face do nariz 6,4 K abaixo da matriz** já exporta os 32,8 W
inteiros por ali. É um ΔT de 6 °C — não precisa de água gelada nem de chiller, e é por isso que a §7 manda medir
a face e não a boca.

### 11.2 O que NÃO fazer, agora com o motivo

* **Não encapar o cabeçote com manta térmica e não pôr abraçadeira de aquecimento nele.** A faixa de aço nu é a
  **única** perda que existe entre a adjunta quente e o ar. Cortar 0,254 W/K empurra a matriz para cima — é o
  contrário do que o defeito pede. (Isso não vale para a adjunta de trás: ali o aquecimento é controlado e é
  onde se mexe na regulagem.)
* **Não baixar a vazão de massa fria como primeira alavanca** (§6-D): cada °C a menos na entrada vale 37,5 W, é
  a alavanca mais forte que existe, e o preço é a pressão já alta e a casca soldando pior no R 0,75 — que é
  justamente onde a manta arrebenta.
* **Não contar com o mostrador de trás como se fosse a matriz** (§10.1.3): ele mede a adjunta.

### 11.3 O teste que fecha a questão, com um IR de R$ 100 e zero usinagem

Partida fria, velocidade travada num ponto, mesma regulagem a manhã inteira. **Seis leituras na face do nariz do
cabeçote** (o anel Ø80→Ø130, Z 95,00) aos 0 / 10 / 20 / 40 / 60 / 90 min, e ao lado o °C do mostrador da adjunta.

* **Se a face do nariz sobe monotonicamente** e o primeiro dente de serra aparece sempre no mesmo °C ⇒ é o bloco
  ensopando. O remédio é **segurar** (pano/gotejador na faixa, faca de ar na manta, e o set-point = esse °C
  menos 10), e a **geometria não é culpada dessa parte** do defeito. Nesse caso o número que sai do teste é a
  primeira especificação térmica que esta matriz nunca teve, e ele vale para as três Jonatha também.
* **Se a face do nariz estiver chata** e o dente vier do mesmo jeito ⇒ não é térmico, e a bola volta para a
  **rev. 31** (freio no centro + alívio nas costas dos extremos + o gota no extremo), que é o que a matrizaria já
  ofereceu e é o caminho do serrilhado nas pontas.
* **Se T(face) subir junto com o mostrador da adjunta** a mesma subida, a fonte é a adjunta e o serviço é
  baixar a zona dianteira dela — meia resposta, sem fabricar nada.

Anotar em cada leitura, junto do °C: espessura nos cinco pontos e o **comprimento da faixa sem tinta** na
ponta (§9.4). Sem esse par (°C × defeito) o número de `T_limiar` não vira regulagem.

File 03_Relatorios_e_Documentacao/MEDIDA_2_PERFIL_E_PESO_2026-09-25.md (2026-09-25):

# 2ª medição na linha: espessura **e** peso, e o número que fecha a saga (2026-09-25)

Ele remedeu os 5 pontos e pesou as amostras: espessura **1,5 · 2,5 · 2,5 · 2,0 · 1,5 mm** e massa
**0,8 · 1,3 · 1,4 · 1,1 · 0,8 g** em `y = −37,5 / −18,75 / 0 / +18,75 / +37,5 mm`. Este documento é a leitura
disso. **Nada no SSOT foi tocado**; no fim está a cota que a medição produz, para virar PRP-0007 se ele quiser.

---

## 1. As duas medições concordam — o perfil é real, não é o paquímetro afundando

| y (mm) | t (mm) | m (g) | t/t_max | m/m_max | desvio peso vs paquímetro |
|---:|---:|---:|---:|---:|---:|
| −37,50 | 1,50 | 0,80 | 0,600 | 0,571 | −4,8 % |
| −18,75 | 2,50 | 1,30 | 1,000 | 0,929 | −7,1 % |
| 0,00 | 2,50 | 1,40 | 1,000 | 1,000 | 0,0 % |
| +18,75 | 2,00 | 1,10 | 0,800 | 0,786 | −1,8 % |
| +37,50 | 1,50 | 0,80 | 0,600 | 0,571 | −4,8 % |

`m/t` nas cinco estações: média **0,539 g/mm** com desvio-padrão de **2,9 %** — se as amostras foram cortadas
do mesmo tamanho, os dois métodos estão contando a mesma história, e é o que os números mostram (afastamento
máximo de 7 %). **Então o perfil não é artefato de medição.** E a 2ª medição confirma a 1ª também na forma:
borda = 1,5 nas duas, centro gordo nas duas.

Subproduto útil: com a densidade de literatura do repo (ρ = 1,25 g/cm³, `04_/masti_epdm_reologia.py`), a área da
sua amostra saiu **≈ 431 mm² (~20,8 × 20,8 mm)**. **Se você me der a área real cortada, eu devolvo a densidade
medida do seu mastique** — que hoje é número de prateleira, nunca foi medido neste projeto, e destravaria
qualquer cálculo de massa por metro.

## 2. O que a manta é, em seção

Integrando o seu perfil pelos 5 pontos (trapézios, passo de 18,75 mm):

| grandeza | medida | nominal do contrato | diferença |
|---|---:|---:|---:|
| seção da manta | **159,4 mm²** | 112,5 mm² (75,00 × 1,50) | **+42 %** |
| velocidade de saída com a vazão de referência (Q = 15.000 mm³/s) | 94 mm/s = **5,6 m/min** | 133 mm/s = **8,0 m/min** | **−30 %** |

Cuidado com o enquadramento, e eu quase errei aqui: a extrusora entrega a vazão que a rosca empurra — com seção
159,4 mm² os mesmos 67,5 kg/h saem a 5,6 m/min. **Você não está queimando material; está vendendo 30 % menos
metro por hora do que a máquina poderia entregar**, porque a seção gorda no meio não deixa a linha correr.
Igualizar em 1,50 nos 75 mm é, além de qualidade, **~42 % mais metro com a mesma extrusora** (se o puxador
acompanhar).

## 3. A assimetria piorou — e isso mudou de diagnóstico

−18,75 mm mede **2,50** e +18,75 mm mede **2,00**: **25 % de diferença entre os dois lados, mesma distância do
centro** (na medição passada: 2,00 × 1,80 = 10 %). E o máximo não está mais no centro: **2,50 aparece em dois
pontos (−18,75 e 0,00)** — a "barriga" está deslocada para o lado A.

Funil simétrico com fenda reta **não faz isso**: no modelo, os dois lados são o mesmo sólido espelhado, seção a
seção (o `avaliacao_matriz3_uniformidade.py` mostra centroide do canal a −0,0071 mm do plano de simetria).
Portanto **tem metal ou alinhamento fora do eixo**: matriz montada girada/fora do centro, assento com cavaco ou
amassado de um lado, bucha/nariz gasto de um lado, alimentação deslocada, ou a manta saindo torcida e você
medindo numa trena que não é perpendicular ao extrudado.

Isto é a pendência nº 1, à frente de qualquer desenho novo: **gire a matriz 180° e remeça os 5 pontos.** Se a
barriga viajar com a matriz, é matriz/assento. Se ficar no mesmo lado da máquina, é máquina — e nenhuma revisão
de matriz resolve.

## 4. A cota que a sua medição produz (e por que ela sai do "sorriso", não do freio)

Assumindo vazão local proporcional à espessura (com a ressalva do §5), com `n = 0,32` do SSOT:

| estação | q / q_máx | resistência local a mais |
|---:|---:|---:|
| ±37,50 | 0,600 | **+17,8 %** |
| +18,75 | 0,800 | +7,4 % |
| −18,75 e 0,00 | 1,000 | — |

Para o centro sair de **2,50 → 1,50 mm** ele precisa passar **1,67× menos material**, o que exige **+18 % de
resistência local = +4,74 bar**, que com o gradiente medido do land (**2,187 bar/mm**) são **2,2 mm de land a
mais no centro**.

E aqui está por que a solução é a **fenda em arco** (a primeira foto dele) e não a janela nas costas nem o tampo
no meio: o arco faz as duas coisas ao mesmo tempo — **afasta o meio da entrada** (mais caminho = mais
resistência onde sobra material) **e aproxima as pontas** (menos caminho onde falta). O alívio nas costas só
abre as pontas, o que neste caso empurraria todo o perfil para 2,5 mm e você teria de esticar a manta no
puxador para voltar a 1,50.

| sagita do arco | land extra no centro | fenda desenvolvida (corda 75,00 intacta) | raio do arco |
|---:|---:|---:|---:|
| 1,00 mm | ~1,00 mm | 75,04 mm (+0,05 %) | 704 mm |
| **2,00 mm** | ~2,00 mm | **75,14 mm (+0,19 %)** | **353 mm** |
| 2,20 mm | ~2,20 mm (o número do §4) | 75,17 mm (+0,22 %) | 326 mm |
| 3,00 mm | ~3,00 mm | 75,32 mm (+0,43 %) | 236 mm |

Ou seja: **o remédio que a sua própria medição pede é um arco de flecha ~2 mm, raio ~350 mm, corda 75,00
inalterada** — a largura da peça não muda, a área da fenda contratada (112,0171 mm²) não muda, o R 0,75 das
pontas não muda, e o custo de usinagem é **a trajetória do fio EDM**, não uma forma nova. É a maior alavanca por
milímetro que existe neste projeto, e veio de um paquímetro e uma balança, não de CFD.

## 5. O que este documento **não** garante

- **q ∝ t** só vale com a velocidade de linha igual na largura. Se a manta cai solta, sem puxador, o swelling
  (que é maior onde sai mais material) infla a diferença de espessura: o centro pode estar passando 1,35× e não
  1,67× o material. Isso não invalida o sinal, mas **faz 2,2 mm ser teto, não alvo** — primeiro passo **1,5 mm de
  flecha**, remeça os 5 pontos, e só abra o arco se o perfil continuar gordo no meio. É iteração com régua, e é
  assim que ele faz na bancada dele.
- O gradiente de 2,187 bar/mm e o ΔP de 26,68 bar são do **método 1D do projeto**, o mesmo dos PRP-0002/0004 —
  ordem de grandeza, não CFD. O número de 203,6 bar do pacote é de outro modelo (com o anel de fuga medido); os
  dois convivem no repo e nenhum dos dois substitui a medição na chapa.
- O arco **não conserta assimetria A≠B** (§3). Se o giro de 180° mostrar que a barriga fica no mesmo lado da
  máquina, a flecha não deve ser desenhada antes de resolver isso.
- Espessura medida com o material "sendo massa", como ele disse: ±0,05 mm por ponto, o que dá ~±3 % no perfil —
  aceitável para dimensionar 1,5–2,0 mm de flecha, insuficiente para discutir 0,1 mm.

## 6. Se ele aprovar, a rev. 31 entra como PRP-0007 com isto dentro

1. **Fenda em arco**: corda 75,00, flecha **1,50 mm** como cota de projeto, com nota de fabricação "ajustável até
   3,00 mm na bancada, só com o perfil de 5 pontos medido em mãos"; raio resultante 469,5 mm (flecha 1,50), R 0,75
   nas pontas preservado.
2. **Chanfro de saída 1,50 → 0,50 × 45°** (land paralelo 9,50): já calculado no repo (PRP-0002) — 27,96 bar
   (+4,8 %) e a parede do lábio de 0,75 para 1,75 mm, o que fecha o P7 da triagem. Mais land também significa
   que a flecha de 1,50 mm entrega um pouco menos de resistência do que a tabela de cima — por isso o começo
   conservador.
3. **Sem janela nas costas e sem freio removível** nesta revisão: com o seu perfil medido, abrir as pontas é o
   remédio errado (empurra tudo para 2,5 mm). Fica registrado como a alternativa, caso o giro de 180° mostre que
   a máquina está limpa e o meio continua gordo mesmo com o arco.
4. Invioláveis confirmados: 75,00 de largura, 1,500 +0,010/−0,000, boca Ø75,60, três estágios, collete EX-031 +
   degrau, sem furo/flange/partição.

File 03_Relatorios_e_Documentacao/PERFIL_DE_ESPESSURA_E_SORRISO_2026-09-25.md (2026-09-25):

# Perfil de espessura medido na linha + as duas soluções que o Fernando mandou (2026-09-25)

Ele mediu a manta em 5 pontos ao longo dos 75 mm, da extremidade A para a B, e mandou duas fotos do Fernando
como exemplos de solução. Este documento converte as duas coisas em número e em decisão. **Nenhuma cota do SSOT
foi tocada**; o que sai daqui é entrada para uma revisão (PRP-0007), não projeto aprovado.

---

## 1. A medição dele, como veio

| estação | A (borda) | A/2 | centro | B/2 | B (borda) |
|---|---:|---:|---:|---:|---:|
| posição `y` na largura | −37,50 | −18,75 | 0,00 | +18,75 | +37,50 |
| espessura medida | **1,50** | **2,00** | **2,57** | **1,80** | **1,50** |

Aviso dele, honesto: *"como o material é massa, não tive tanta precisão"*. É paquímetro em mastique mole, e o
material cede sob a ponta. Assumindo velocidade de linha igual em toda a largura (a manta é um sólido contínuo,
não dá para o centro correr mais que a ponta sem esticar), espessura ∝ vazão local:

| estação | q / q_centro | resistência local extra (com `n = 0,32`) |
|---|---:|---:|
| ±37,50 (bordas) | 0,584 | **+18,8 %** |
| −18,75 | 0,778 | +8,4 % |
| +18,75 | 0,700 | +12,1 % |
| 0 (centro) | 1,000 | — |

**É aqui que a coisa fecha com a conversa toda:** o centro passa **71 % mais material** que as bordas, e a
resistência que explica isso é de só **19 %**. É o efeito `1/n = 3,125` do mastique: desequilíbrio pequeno de
camino, defeito grande na peça. E o inverso também vale - uma correção de resistência de ~19 % já conserta a
peça inteira.

Limite que tem de ficar escrito: se a manta **cai solta na mesa, sem puxador**, espessura não é vazão (o swelling
varia com a taxa de cisalhamento e engorda mais onde sai mais). Nesse caso 19 % é teto, não medida - e a
iteração de bancada (abre um pouco, mede de novo) é o método, não o cálculo.

## 2. O que cada alavanca custa, com o número dele

| caminho | o que faz com a resistência | conta no ΔP do projeto (26,68 bar no método 1D) | efeito na produção |
|---|---|---|---|
| **frear o centro** (o tal bloco) | +18,8 % no centro | **+5,02 bar** | vazão média 0,729 → 0,584 = **80 % da produção atual** |
| **abrir as bordas** (o alívio) | −15,8 % em cada borda | −4,2 bar nas bordas, no orçamento dos **6,73 bar** que o funil+entrada gastam (75 % disso) | vazão média 0,729 → 1,000 = **137 % da produção atual**, ou a mesma produção com menos pressão |

Ou seja, com o número dele a regra sai mais dura do que eu disse antes: **o freio compra informação ao preço de
um quinto da linha; o alívio é o que se fabrica.** E o alívio cabe no orçamento do funil - apertado, mas cabe.
É o argumento objetivo para não mandar "só um freio" como solução definitiva.

## 3. As duas fotos do Fernando (o que eu vejo nelas, sem inventar)

* **Disco azul, fenda em "sorriso", com o relevo `90 x 2mm` na face.** Fenda **curva no plano**, os dois furos
  redondos simétricos acima do arco (a ferramenta de virar a matriz, como ele mesmo explicou). A cor azulada é
  têmpera/óxido de revenimento - peça tratada termicamente. É a solução geométrica: **curvando a fenda no plano
  você muda o caminho do material sem tocar na folga de 1,50** - as pontas chegam mais perto da entrada e o
  centro mais longe, que é exatamente o +19 %/−16 % que a tabela acima pede.
* **Disco de aço com fenda reta, termina em gota nas duas pontas, e um tampo quadrado em relevo no centro**
  (as duas setas verdes apontam o tampo e a fenda). O tampo é o freio: um calço no centro, do lado de dentro,
  obrigando o material a contornar para entrar na boca do meio. **E as pontas em gota são o "abrir mais nas
  extremidades"**, feito na própria fenda - as duas bengalas da fenda são mais largas que o corpo dela.

Sobre o sorriso, a conta que torna isso fabricável sem briga com a peça: **a corda continua 75,00**, então a
largura da manta não muda; o que cresce é o comprimento desenvolvido da fenda.

| sagita do arco | fenda desenvolvida | raio do arco |
|---:|---:|---:|
| 1,00 mm | 75,04 mm (+0,05 %) | 704 mm |
| 2,00 mm | 75,14 mm (+0,19 %) | 353 mm |
| 3,00 mm | 75,32 mm (+0,43 %) | 236 mm |
| 5,00 mm | 75,89 mm (+1,19 %) | 143 mm |

Curvar 2 ou 3 mm custa 0,2 a 0,4 % de comprimento de fenda e **zero de usinagem extra** (é trajetória do fio
EDM, não forma nova). É o ajuste com a maior alavanca por milímetro de que a gente dispõe. O valor da sagita não
é meu para escolher: é a iteração - começa-se pequeno (1 mm), mede-se o perfil de novo, abre-se mais.

## 4. O que a medição dele grita e não é sobre fluxo

**A e B são diferentes:** −18,75 mm mede **2,00** e +18,75 mm mede **1,80** - 10 % de diferença entre os dois
lados, mesma distância do centro. Funil simétrico + fenda reta **não produz assimetria**: no modelo do projeto
os dois lados são o mesmo sólido espelhado. Isso é coisa fora do eixo - matriz montada girada/fora do centro,
assento com cavaco, bucha do cabeçote gasta de um lado, alimentação do funil deslocada, ou a mesa de saída
puxando torto. **Antes de cortar metal, gire a matriz 180° e meça os mesmos 5 pontos de novo**: se a assimetria
mudar de lado com a matriz, é a matriz (ou o assento dela); se ficar no mesmo lado da máquina, é a máquina - e aí
nenhuma revisão de desenho conserta nada.

## 5. Como medir isto direito, sem paquímetro em cima de massa

Corte 5 amostras quadradas na largura (50 × 50 mm, nas mesmas posições de hoje), seque, e pese. Com
ρ = 1,25 g/cm³ (`04_/masti_epdm_reologia.py`), 50 × 50 × 1,50 mm pesa **4,688 g**:

* balança de **0,01 g** resolve **0,0032 mm** de espessura - 3 vezes melhor que um paquímetro em material mole,
  e sem achatar a amostra;
* com 30 × 30 mm (1,688 g) ainda dá 0,0089 mm.

E o critério de aceite passa a ser o que ele quer, não o que o modelo consegue: **a espessura medida nos 5 pontos
com o mesmo desvio que a boa manta de PVC dele aceita.** Esse número só ele pode dar; é a única cota nova que
preciso dele antes de desenhar a rev. 31.

## 6. Rev. 31, com tudo isso em cima da mesa (proposta, não projeto)

Invioláveis mantidos: fenda 75,00 × 1,500 +0,010/−0,000 com R 0,75, boca de entrada Ø75,60, envelope de 3
estágios, collete EX-031 + degrau, sem furo/flange/partição.

1. **Fenda em arco** (sorriso) com corda 75,00 e sagita inicial **1,00 mm**, marcada no desenho como
   *cota de ajuste*: "abrir mais, até 3,00, só na bancada e com o perfil medido na mão".
2. **Janela de alívio rasa na face de entrada**, corrida atrás da fenda, fundo **mais próximo da boca nas bordas
   que no centro** - que é o "mais abertas nas pontas, fechado no centro" dele. Profundidade inicial definida
   contra o +18,8 %, com aço sobrando para ajustar depois.
3. **Chanfro de saída 1,50 → 0,50 × 45°** (land paralelo 9,50): já calculado no repo (PRP-0002), 27,96 bar
   (+4,8 %) e a parede do lábio de 0,75 para 1,75 mm, o que também fecha o P7 da triagem. Menos espaço para o
   desequilíbrio nascer, porque o land passa de 69,7 % para 74,3 % do ΔP.
4. **Sem freio removível no desenho** - o freio é o teste dele, não a solução nossa (custa 20 % da linha).
5. Antes de fechar: **ver o §4** (assimetria). Se for máquina, a lista acima muda de prioridade: conserta-se o
   assento primeiro e talvez nem precise de arco.

Nada disso entra em `cad_die_parameters.json` nem em STEP sem virar **PRP-0007** com os cálculos do método do
projeto por trás, e sem CFD 3D quando a escolha for asa de cabide (aí sim: o D3 mostrou +141 % de ΔP).

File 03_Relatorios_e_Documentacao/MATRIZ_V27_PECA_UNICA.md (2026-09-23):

# Matriz Jonatha v27.0 como peça única — o que mudou, medido

Gerado por `04_Dados_SSOT_e_Scripts/gerar_matriz_v27_peca_unica.py` em 2026-09-13. **ATUALIZAÇÃO DA MESMA RODADA: esta variante foi promovida a oficial como v29.0** — ver `07_CAD_Matrizes/Matriz_Jonatha_v29_OFICIAL/` e o pacote de fábrica `08_Pacote_Usinagem_v29/` (o STEP é byte-idêntico ao desta pasta; a v27.0 bipartida continua selada no disco). Originalmente esta peça era uma **variante derivada**: o master continuava sendo `01_CAD_MatrizJonatha_Oficial/MatrizJonatha.step` (sha256 `7f26c5c5ba238a12667f2bdf…`, regra 1) e a peça única morava em `07_CAD_Matrizes/Matriz_Jonatha_v27_Peca_Unica/`. O texto abaixo é o da medição original, que continua valendo: a geometria da v29.0 é esta, byte a byte.

## A peça

| grandeza | master bipartido | peça única | o que é |
|---|---|---|---|
| sólidos no arquivo | 2 (Body_A + Body_B) | **1** | sem par, sem jogo de montagem |
| aço | 469001,7 mm³ | **469303,2 mm³** | **+301,5 mm³** = as bolhas seladas e os furos de alinhamento que deixaram de existir (re-medido nesta rodada; o valor anterior, 351,9, era de conta de cabeça, não de medição) |
| massa | 3,6817 kg | **3,6840 kg** | ρ = 7,85 g/cm³ |
| bolhas seladas dentro do aço | 2 (G-03 do auditor) | **0** | os furos de pino cegos deixaram de existir porque não há mais o que alinhar |
| canal (funil + fenda) | 213945,1 mm³ | **213945,1 mm³** | o caminho do material é o mesmo |
| fenda no land (Z = 107,00) | 75,000 × 1,500 mm, R 0,75, área 112,0171 mm² | **75,000 × 1,500 mm, R 0,75, área 112,0171 mm²** | Δ de área = 0,000000 mm² — o produto é o mesmo |
| boca de entrada | Ø 75,60 mm | **Ø 75,60 mm** | a restrição do acoplamento com a extrusora é Ø 75,60 — e não mudou |
| envelope | Ø93,00 Z 0,00..69,90 · Ø89,50 Z 69,90..80,70 · Ø79,50 Z 80,70..109,00 | idêntico | senta no mesmo furo do cabeçote EX-030 |
| boca de saída (Z = 108,99) | 78,000 × 4,500 mm, área 346,6543 mm² (meia-lua (R = espessura/2)) | **78,000 × 4,500 mm, área 346,6543 mm² (meia-lua (R = espessura/2))** | o chanfro 1,50 × 45° abre a boca do mesmo jeito nas duas |
| BRepCheck | — | sólido válido, **0** cara(s) e **0** aresta(s) inválida(s) em **22 caras / 45 arestas** (o par bipartido tem 43 caras / 97 arestas; o 90 que estava aqui contava cada aresta duas vezes, uma por face) | | abre limpa em qualquer CAD (o defeito achado na v28.1 não se repete aqui) |

## O que a peça única tira do produto

A bipartição corta o canal por dentro, no plano Y = 0 — que é o **meio da espessura** da manta. Onde esse plano encontra as paredes do canal nasce a linha de costura que aparece na peça extrudada. Medido no master:

* área de junta metal-metal no plano Y = 0: **1.513,1 mm² por metade** (duas tiras, 758,0 + 755,1), **1.538,2 mm²** na `Body_A` (as duas pastilhas de 12,6 mm² do alinhamento) e **3.051,3 mm²** somando os dois lados no arquivo do par — re-medido com `abre()` + filtro de cara PLANE com normal ±Y e caixa em y = 0; o valor de 759,5 mm² citado antes era uma única tira dessas, não a junta inteira;
* a seção do canal no plano de partição: **8.204,4 mm²** ocupando 78,000 mm em X por 109,000 mm em Z, com perímetro de costura de **372,8 mm**;
* **2 linha(s)** de costura correndo nas bordas da manta (x = ±37,50), de ponta a ponta do canal (o perímetro de 372,8 mm da costura é o que faz a junta aparecer no produto, não a área). É por isso que a serra aparece *na borda* e não na face: o plano de partição é perpendicular às faces grandes e paralelo às bordas.

Na peça única esses três números são **zero**: não há junta, logo não há degrau nem rebarba de junta, e o que sobrar de serrilha na borda não vem mais da matriz bipartida — passa a ser processo (τ na parede contra o limiar de raspado, 0,14 MPa da literatura) ou desenho do lábio. É exatamente a separação que a simulação 3D vai fechar.

## Fabricabilidade: o canal tem de ser feito por acesso reto das duas faces

Sem as duas metades, o único jeito de abrir o funil e a fenda é entrar por elas. Testei cada cara do vazio em linha reta pela entrada (Z < 0) e pela saída (Z > 109,00):

| # | tipo de cara | área (mm²) | centro (mm) | vista pela entrada | vista pela saída | leitura |
|---|---|---|---|---|---|---|---|
| 1 | PLANE | 4489 | 0,00, 0,00, 0,00 | 100,0% | 100,0% | entrada+saida |
| 2 | BSPLINE | 93 | 37,45, -0,38, 49,60 | 100,0% | 100,0% | entrada+saida |
| 3 | BSPLINE | 9184 | 0,00, -7,88, 43,93 | 100,0% | 0,0% | entrada |
| 4 | BSPLINE | 91 | -37,46, -0,38, 49,60 | 100,0% | 100,0% | entrada+saida |
| 5 | BSPLINE | 90 | -37,46, 0,38, 49,60 | 100,0% | 100,0% | entrada+saida |
| 6 | BSPLINE | 9213 | 0,08, 7,77, 43,85 | 100,0% | 0,0% | entrada |
| 7 | BSPLINE | 0 | 37,80, 0,00, 0,21 | 100,0% | 100,0% | entrada+saida |
| 8 | BSPLINE | 54 | 37,45, 0,19, 50,00 | 100,0% | 100,0% | entrada+saida |
| 9 | CYLINDER | 20 | 36,85, 0,00, 103,25 | 100,0% | 100,0% | entrada+saida |
| 10 | PLANE | 625 | 0,00, -0,75, 103,25 | 100,0% | 100,0% | entrada+saida |
| 11 | CYLINDER | 20 | -36,85, 0,00, 103,25 | 100,0% | 100,0% | entrada+saida |
| 12 | PLANE | 625 | 0,00, 0,75, 103,25 | 100,0% | 100,0% | entrada+saida |
| 13 | CONE | 10 | 37,57, -0,00, 108,51 | 100,0% | 100,0% | entrada+saida |
| 14 | PLANE | 156 | 0,00, -1,50, 108,25 | 0,0% | 100,0% | saida |
| 15 | CONE | 10 | -37,57, 0,00, 108,51 | 100,0% | 100,0% | entrada+saida |
| 16 | PLANE | 156 | 0,00, 1,50, 108,25 | 0,0% | 100,0% | saida |
| 17 | PLANE | 347 | 0,00, 0,00, 109,00 | 100,0% | 100,0% | entrada+saida |

**0 de 17** caras do canal não têm acesso reto nem pela frente nem por trás. Todas as caras são alcançáveis de um dos dois lados: a peça única é usinável com o canal por frente e a fenda por trás, sem necessidade de junta.

## Montagem no cabeçote completo, com flange

`Cabecote_EX-030_com_Matriz_Jonatha_v27_Peca_Unica.step` — 2 sólidos no arquivo (1 cabeçote + 1 peça única, sem booleano), volume somado 2039642,7 mm³, **interferência com o metal do cabeçote = 0,0000 mm³**, face de saída em Z = 109,00 (protrusão +14,00 mm além da face do nariz). O encaixe é o mesmo da bipartida: folga radial de Ø 93,00 no furo Ø 95,00 e assento no degrau, e o anel de fuga entre matriz e cabeçote continua existindo igual — ele não vem da bipartição.

## Consequências e o que não muda

* **Decisão D2 intocada:** chanfro de saída 1,50 × 45° e land paralelo 8,50 mm do master. Nada de geometria do produto foi alterado nesta rodada — só a construção da peça.
* **Fixação:** o collete EX-031 e o degrau do cabeçote continuam sendo o que segura a matriz; os pinos de alinhamento somem da conta junto com os furos (a força de abertura medida do plano de partição, 55,7 kN, deixa de existir porque não há plano de partição).
* **Anel de fuga:** a folga de 1,00/0,25/0,25 mm entre a OD da matriz e o furo do cabeçote é do encaixe, não da bipartição — continua igual nas duas peças, e é a rota que a simulação precisa resolver.
* **Promoção:** a peça única **não** é o master. Quando ele quiser, se ela entra no lugar da v27 bipartida, é preciso re-sear o baseline (ato do auditor, com o método novo) — e aí vale aproveitar para consertar o `Body_B` da v28.1, que tem uma cara degenerada achada pela auditoria de correlações.

## Revisão de 2026-09-22: Ø novos, ±0,5 e a v30 faceada ao nariz

O dono mandou alterar os três Ø do envelope e registrar ±0,5 em toda cota alterada; o modelo e o desenho foram re-gerados juntos (`04_/gerar_revisoes_v29_v30.py`), com o canal de fluxo herdado 1:1 do STEP aprovado. Medido nos dois STEP novos:

| | v29 (re-feita) | v30 (nova) |
|---|---|---|
| Ø dos três estágios | 94,00 / 89,00 / 79,00 | 94,00 / 89,00 / 79,00 |
| comprimento | 109,00 (inalterado) | 95,00 |
| land / fenda / área no land | 8.500 mm · 75,0000 × 1.500 · 112,0171 mm² | idêntico: 8.500 mm · 75,0000 × 1.500 · 112,0171 mm² |
| faces / sólidos / BRep | 22 / 1 / válido | 22 / 1 / válido |
| volume de aço → massa | 477050,9 mm³ → 3,745 kg | 438509,9 mm³ → 3,442 kg |
| canal de fluxo (vazio) | 213945,1 mm³ | 183862,6 mm³ (funil comprimido por s = 0,858586) |
| protrusão além do nariz do cabeçote | +14,00 mm | +0,00 mm |
| interferência com o cabeçote | 0,0000 mm³ | 0,0000 mm³ |
| folga radial nos 3 estágios | 0,50 / 0,50 / 0,50 mm | 0,50 / 0,50 / 0,50 mm |
| material | aço 1045 + indução/nitretação no land | aço 1045 + indução/nitretação no land |

Consequências que precisam continuar escritas junto da peça:

1. **o envelope deixou de ser idêntico ao da Matriz 2 (Gedeon)** — era essa a justificativa dos Ø93,00/89,50/79,50; agora a coincidência acabou e a peça é própria.
2. **a folga anular nos três estágios virou 0,50 mm** (antes 1,00 / 0,25 / 0,25). Isso é o que limita a fuga de material para trás; o efeito no escoamento foi re-medido com o modelo de rotas (ver `SIMULACAO_ROTAS_E_COMPRIMENTO.md`, seção de 2026-09-22).
3. **±0,5 no Ø de envelope é cota de folga, e é aí que ela cobra**: o Ø94,00 com +0,5 vira 94,50 num furo Ø95,00, então a matriz **ainda entra** (folga radial de 0,25 mm no pior caso, não zero). O que muda é a fuga para trás. Re-medido no modelo de rotas com o mesmo mastique (Q = 15.000 mm³/s, os três estágios com o mesmo valor, comprimentos congruentes 69,90 / 10,80 / 14,00 mm): com folga 0,50 (nominal) escapam 0,273 % pela v29 e 0,212 % pela v30; folga 0,25 (Ø no limite de −0,5) derruba para 0,007 % e 0,005 %; folga 0,75 (Ø no limite de +0,5) leva a 2,323 % e 1,810 % - 8,5 vezes o nominal, porque a fuga escala com o cubo da folga. A pressão de produto mal sente (219,7 bar / 203,6 bar; o land manda), mas 348 mm³/s voltando pelo anel é material parado queimando na entrada. A decisão de manter ±0,5 é dele; o número do pior caso fica registrado em `04_Dados_SSOT_e_Scripts/revisoes_2026_09_22_folgas_limites.json`.
4. **o 1045 com tratamento na fenda pode mover 1,500** (tolerância +0,010/−0,000): mede-se antes e depois do tratamento, e o retrabalho é re-passar o fio, não aceitar fora.
5. a face de saída da v30 coincide com a face do nariz (Z 95,00, medido). Com +0,5 mm de sobra na cota do comprimento a matriz passaria 0,5 mm para fora do nariz — por isso o pacote anota que, se a fábrica quiser apertar, o aceitável prático é 95,00 −0,50/+0,00.

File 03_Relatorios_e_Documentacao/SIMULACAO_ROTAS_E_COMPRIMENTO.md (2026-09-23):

# Rotas do mastique: passa pela fenda ou escapa pelo anel — e 109 mm × 100 mm

Gerado por `04_Dados_SSOT_e_Scripts/simular_rotas_e_comprimento.py`. Geometria **medida nos STEP** (o vazio da peça inteira, seção de 0,02 mm varrendo Z) e folgas do anel lidas do bloco C4 da auditoria de correlações. Reologia de `04_/masti_epdm_reologia.json` (banda ancorada em η(100 s⁻¹), com as quatro fontes). Vazão do projeto: 15000 mm³/s = 15,0 cm³/s (a do SSOT).

## A resposta, direta

**Deixa em 109 mm.** Encurtar para 100 mm não mexe em nada que gere pressão — o funil e o land ficam intactos, os 9,00 mm a menos são aço liso do meio da peça — e **encurta o caminho de fuga**: o anel entre a matriz e o furo do cabeçote é a rota pela qual o material escapa para trás, e anel mais curto tem menos resistência, então escapa *mais*. É esse o sinal que a tabela de cenários mostra.

## O que cada matriz exige, com o mesmo material e a mesma vazão

| matriz | comprimento | **land paralelo medido** | área no land | ΔP típico (bar) | banda baixa | banda alta | escapa pelo anel | saída (m/min) | τ no land (MPa) | raspado? |
|---|---|---|---|---|---|---|---|---|---|---|
| `Copo (original)` | 80,70 mm | **9,75 mm** | 112,0170 mm² | **211,2** | 63,4 | 633,7 | 1,327 % | 7,89 | 0,794 | SIM |
| `Gedeon CERTA (a sua)` | 109,00 mm | **88,50 mm** | 112,0170 mm² | **963,0** | 288,9 | 2.888,9 | 9,140 % | 7,27 | 0,775 | SIM |
| `Jonatha v27.0 (bipartida)` | 109,00 mm | **8,50 mm** | 112,0170 mm² | **219,9** | 66,0 | 659,7 | 0,067 % | 7,99 | 0,797 | SIM |
| `Jonatha v29.0 (peça única)` | 109,00 mm | **8,50 mm** | 112,0170 mm² | **219,9** | 66,0 | 659,7 | 0,067 % | 7,99 | 0,797 | SIM |

**Leitura da tabela: o que separa as matrizes é o comprimento de land, não o comprimento da peça.** A fenda da Gedeon é passante — medida, ela tem land paralelo de **88,50 mm** contra **8,50 mm** da Jonatha — e o dP do land é linear no comprimento do land: 963,0 bar contra 219,9 bar, e a fração que escapa pelo anel sobe de 0,067 % para **9,140 %** (136×). É a versão numérica do "volta pelo funil": não é que o funil puxe o material para trás, é que a fenda da Gedeon exige pressão que a linha não tem, e o material procura o caminho de menor resistência.

## Os cenários de comprimento e de folga (Jonatha v29.0)

| cenário | ΔP típico (bar) | escapa pelo anel | saída (m/min) | o que faz com a volta pelo funil |
|---|---|---|---|---|
| 109 mm (como está) | 219,9 | 0,067 % | 7,99 | corta a fuga sem encostar no produto |
| 100 mm (encurtar a peça) | 219,9 | 0,071 % | 7,99 | piora: o anel encurta e a fuga fica mais fácil |
| 100 mm + pinça de 0,15 na saída do anel | 219,9 | 0,036 % | 8,00 | piora: o anel encurta e a fuga fica mais fácil |
| 109 mm + land 6,00 | 196,2 | 0,045 % | 8,00 | menos pressão exigida da linha — o land é a alavanca |
| 109 mm + land 5,00 | 186,7 | 0,039 % | 8,00 | menos pressão exigida da linha — o land é a alavanca |
| 109 mm + anel apertado nos 3 estágios (0,40/0,15/0,15) | 219,9 | 0,003 % | 8,00 | corta a fuga sem encostar no produto |
| 109 mm + anel apertado só no último estágio (0,10) | 219,9 | 0,002 % | 8,00 | corta a fuga sem encostar no produto |

## O que ainda falta para isso ser afirmação de processo, e não prévia

* O funil é aproximado por placas de abertura média 6,00 mm (o `manifold_central_depth_mm` do SSOT) no comprimento medido. O que diz se há zona morta dentro do funil é a CFD 3D no volume dele (gmsh + scikit-fem: ambiente montado e testado, é o item deixado para a próxima etapa). Esta conta separa as rotas; não resolve recirculação.

* `escapa pelo anel` é a vazão que o anel leva sob o **mesmo ΔP** das duas rotas: mede a fuga entre matriz e furo, não a velocidade com que o material volta pelo funil de alimentação da extrusora — isso depende da curva da rosca, que não está no repo.

* A reologia é banda de literatura (η de 1,500 a 15,000 Pa·s em 100 s⁻¹), não reômetro do lote. O que é independente da banda: **a ordem das matrizes e o sinal de cada cenário** (as três curvas dão a mesma hierarquia, porque tudo escala com K).

* O limiar de raspado (τ ≥ 0,14 MPa, literatura de capilar) dispara para **todas** as matrizes nesta vazão (15 cm³/s ≈ 9× a da linha análoga da literatura). Ou a linha real opera com o material mais quente/mais plastificado que a banda baixa, ou o limiar do produto plano é maior que o do capilar. É pergunta para o reômetro, não para o CAD.

Janela de referência da linha análoga (EPDM, perfil): ΔP de matriz **2,1–9,4 MPa** a 41–128 g/min; o repo tinha 41,9 bar de ΔP 1D calibrado para a v27.0, que é da ordem da janela — a banda baixa desta tabela bate com ela.

## Re-medido em 2026-09-22 com as folgas novas

Re-executado o mesmo modelo (mesmo mastique, mesma vazão Q = 15000 mm³/s, as três curvas de reometria do arquivo) com o anel de fuga **medido nas montagens novas** e a rota da fenda medida no STEP de cada revisão. Nada foi copiado da tabela anterior.

| revisão | folgas do anel (mm) × comprimento congruente | dP (tipico) | escapa pelo anel | v de saída | τ no land |
|---|---|---:|---:|---:|---:|
| v29 | 0,50 × 69,9 (Ø94,5) + 0,50 × 10,7 (Ø89,5) + 0,50 × 14,0 (Ø79,5) | **219,7 bar** | 0.277 % | 7,98 m/min | 0.797 MPa |
| v30 | 0,50 × 69,9 (Ø94,5) + 0,50 × 10,7 (Ø89,5) + 0,50 × 14,0 (Ø79,5) | **203,6 bar** | 0.215 % | 7,98 m/min | 0.797 MPa |

Leitura honesta: abrir a folga dos estágios 2 e 3 de 0,25 para 0,50 mm **triplica a fração que escapa para trás** nos cenários com a matriz comprida, e o encurtamento da v30 devolve um pouco (menos trecho de anel dentro do nariz). A fenda em si não muda nada: land, área e chanfro são os mesmos medidos, então a vazão de produto e a espessura da manta continuam as da tabela acima. Quem decide a uniformidade da manta é a coaxialidade dos estágios, não o Ø.

Números completos em `04_Dados_SSOT_e_Scripts/revisoes_2026_09_22_simulacao.json` (as três curvas, trecho por trecho).

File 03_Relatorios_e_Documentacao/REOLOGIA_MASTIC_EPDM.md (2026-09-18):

# Reologia do mastique resistivo à base de EPDM — o que a simulação vai usar

Você definiu o material (*"mastic resistivo não linear a base de EPDM"*) e mandou buscar valores de literatura. Este arquivo é o resultado, gerado por `04_Dados_SSOT_e_Scripts/masti_epdm_reologia.py`: **uma banda, não um número**, porque reômetro deste lote não existe no repo e inventar precisão aqui seria o pior tipo de erro.

## Os três jogos

| nível | K (Pa·sⁿ) | n | η(0,1 s⁻¹) | η(10 s⁻¹) | η(100 s⁻¹) | η(1000 s⁻¹) (Pa·s) | o que representa |
|---|---|---|---|---|---|---|---|
| `otimista` | 37678 | 0.30 | 188838.8 | 37678.3 | 7517.8 | 299.3 | banda baixa: mastique quente e bem plastificado - o minimo plausivel para um resistivo |
| `tipico` | 125594 | 0.30 | 629462.7 | 125594.3 | 25059.4 | 997.6 | centro da faixa: o que a literatura de composto EPDM + negro de fumo pede em 10^2 1/s |
| `pessimista` | 376783 | 0.30 | 1888388.1 | 376783.0 | 75178.1 | 2992.9 | banda alta: mastique frio e muito carregado - o cenario em que nada passa pela fenda |

Ponto de partida: o SSOT traz K = 18500 Pa·s^0.32 a 190 °C (EPR/XLPE/PVC modificado). Deslocado para 90 °C com a Ea/R do próprio SSOT, dá K = 231512; os três níveis acima são 3×, 8× e 20× esse valor — que é a ordem de grandeza entre um masterbatch e um mastique resistivo muito carregado.

## Os dois critérios que a simulação tem de responder

1. **passa ou volta** — a queda de pressão necessária na fenda de cada matriz, comparada à janela da linha: no processo análogo medido na literatura, matriz de perfil EPDM opera com **2,1–9,4 MPa** a 41–128 g/min. Acima do topo, o material procura outra saída; e neste conjunto existe exatamente outra saída (medida na C4 da auditoria de correlações: anel com folga de 1,00/0,25/0,25 mm, contínuo do bico até a entrada da matriz).
2. **raspa ou não raspa** — a tensão de cisalhamento na parede na boca de saída. O limiar de *sharkskin* é **0,14 MPa** (escorregamento a partir de ~0,1 MPa; com auxiliar de processamento, até ~0,5 MPa). Onde a parede passa disso nos **cantos** da fenda, é aí que a serra aparece — e é por isso que a forma da borda (estádio × canto vivo) foi medida na auditoria, na seção a 0,01 mm da face de saída: Copo e Gedeon CERTA dão **112,017 mm²** = estádio 75,00 × 1,50 com R 0,75; Jonatha v27 e v28.1 dão **346,654 mm²** = o mesmo estádio já aberto pelo chanfro de saída (boca 78,00 × 4,50); a `MatrizDesenvolvimento` histórica dá **351,0 mm²** = o retângulo 78,00 × 4,50 **sem arredondamento nenhum** — canto vivo, onde a manta rasga. É a diferença geométrica que a sua serra na borda pede para olhar primeiro.

## O que não é medido aqui

* não há reômetro deste lote específico no repo: K é a família do SSOT deslocada em temperatura e multiplicada por 3/8/20 — os três números têm de ser lidos como intervalo
* o limiar de escoamento (tau_y) é faixa de literatura, não medida: se ele existir de fato, o miolo da fenda para de escoar antes da borda, e é aí que a serra nasce
* a temperatura real do seu cabeçote (EX-030) não foi medida; usamos a da linha análoga (90 C)

## Fontes

* dP de matriz 2,1-9,4 MPa; 41-128 g/min; matriz a 70 C, cabeça 79-87 C (EPDM, perfil) — Polymers 18(9):1122 (2026) — Numerical Investigation of Die Swell Behavior in EPDM Rubber Extrusion ([link](https://www.mdpi.com/2073-4360/18/9/1122))
* sharkskin em tau_parede >= 0,14 MPa; escorregamento em ~0,1 MPa; limiar sobe a ~0,5 MPa com auxiliar de processamento/BN — J. Vlachopoulos, The Role of Rheology in Polymer Extrusion ([link](http://www.polydynamics.com/Rheology.pdf))
* composto cru: lei-potência boa em faixa larga de gama, Herschel-Bulkley melhor no total — Journal of Rheology 70, 65 (2026) — Viscosity characterization of uncured rubber compounds via uniaxial compression ([link](https://pubs.aip.org/sor/jor/article/70/1/65/3374181/))
* EPDM com negro de fumo: viscosidade/tau_Parede/die swell medidos em capilar; Cox-Merz não vale — Polymer 39 (1998) — Rheological properties of EPDM compound ([link](https://www.sciencedirect.com/science/article/abs/pii/S0032386197002310))

Gerado em 2026-09-13. Os números de geometria citados vêm de `03_/AUDITORIA_CORRELACOES_STEP.md` (medidos nos STEP).

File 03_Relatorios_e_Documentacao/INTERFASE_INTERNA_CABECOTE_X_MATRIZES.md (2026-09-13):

# Parte interna do cabeçote EX-030 × as cinco matrizes — comparado por medida

Gerado por `medir_perfis_matrizes_x_cabecote.py`. Escada interna do cabeçote medida do construtor `verificar_interface_cabecote.cabecote`, no referencial da matriz (face do nariz em Z = 95,00, fundo do bolso em Z = 0):

| furo do cabeçote | Ø | de Z | até Z | profundidade |
|---|---|---|---|---|
| bolso de fixação (onde a bucha aperta a banda) | Ø95,00 | 0,00 | 70,00 | 70,00 mm |
| rebaixo traseiro do piloto - não restringe a matriz | Ø105,00 | 0,00 | 3,00 | 3,00 mm |
| degrau - assento do ombro da matriz | Ø90,00 | 70,00 | 81,00 | 11,00 mm |
| furo do nariz (por onde a película sai) | Ø80,00 | 81,00 | 95,00 | 14,00 mm |

## O que cada matriz é, medida no STEP dela

| matriz | compr. | Ø máx | fim da banda Ø93 | folga axial banda↔degrau | face de saída | vão de furo Ø80 aberto à frente da saída |
|---|---|---|---|---|---|---|
| Matriz 1 - Copo (original, a que o cabecote foi feito em volta) | 80,70 | 93,00 | 69,909 | 0,091 | 80,700 | 14,00 mm = 70372 mm³ de furo, **70372 mm³** sem metal da matriz dentro |
| Matriz 2 - Gedeon (a maior, que o usuario diz que entra) | 109,00 | 93,00 | 69,909 | 0,091 | 109,000 | 0,00 mm = 0 mm³ de furo, **0 mm³** sem metal da matriz dentro |
| Matriz Gedeon CERTA (o arquivo do usuario, entregue como esta) | 109,00 | 93,00 | 69,909 | 0,091 | 109,000 | 0,00 mm = 0 mm³ de furo, **0 mm³** sem metal da matriz dentro |
| Matriz Desenvolvimento | 109,00 | 93,00 | 69,909 | 0,091 | 109,000 | 0,00 mm = 0 mm³ de furo, **0 mm³** sem metal da matriz dentro |
| Matriz Jonatha v27.0 (oficial aprovada) | 109,00 | 93,00 | 69,909 | 0,091 | 109,000 | 0,00 mm = 0 mm³ de furo, **0 mm³** sem metal da matriz dentro |
| Matriz Jonatha v28.1 (proposta DFM) | 109,00 | 93,00 | 69,909 | 0,091 | 109,000 | 0,00 mm = 0 mm³ de furo, **0 mm³** sem metal da matriz dentro |

## Estágio por estágio: em qual furo do cabeçote cai cada parte da matriz

Medido no assento natural (o encosto em que a matriz não interfere):

| matriz | estágio da matriz | furo do cabeçote onde ele cai | folga radial | entra? |
|---|---|---|---|:--:|
| Matriz 1 - Copo (original, a que o cabecote foi feito em volta) | Ø93,00 em Z 0,00..69,80 | Ø95,00 (Z 0,00..70,00) | 1,000 mm | sim |
| Matriz 1 - Copo (original, a que o cabecote foi feito em volta) | Ø89,50 em Z 70,00..80,60 | Ø90,00 (Z 70,00..81,00) | 0,250 mm | sim |
| Matriz 2 - Gedeon (a maior, que o usuario diz que entra) | Ø93,00 em Z -0,00..69,80 | Ø95,00 (Z 0,00..70,00) | 1,000 mm | sim |
| Matriz 2 - Gedeon (a maior, que o usuario diz que entra) | Ø89,50 em Z 70,00..80,60 | Ø90,00 (Z 70,00..81,00) | 0,250 mm | sim |
| Matriz 2 - Gedeon (a maior, que o usuario diz que entra) | Ø79,50 em Z 80,80..109,00 | Ø80,00 (Z 81,00..95,00) | 0,250 mm | sim |
| Matriz Gedeon CERTA (o arquivo do usuario, entregue como esta) | Ø93,00 em Z -0,00..69,80 | Ø95,00 (Z 0,00..70,00) | 1,000 mm | sim |
| Matriz Gedeon CERTA (o arquivo do usuario, entregue como esta) | Ø89,50 em Z 70,00..80,60 | Ø90,00 (Z 70,00..81,00) | 0,250 mm | sim |
| Matriz Gedeon CERTA (o arquivo do usuario, entregue como esta) | Ø79,50 em Z 80,80..109,00 | Ø80,00 (Z 81,00..95,00) | 0,250 mm | sim |
| Matriz Desenvolvimento | Ø93,00 em Z -0,00..69,80 | Ø95,00 (Z 0,00..70,00) | 1,000 mm | sim |
| Matriz Desenvolvimento | Ø89,50 em Z 70,00..80,60 | Ø90,00 (Z 70,00..81,00) | 0,250 mm | sim |
| Matriz Desenvolvimento | Ø79,50 em Z 80,80..109,00 | Ø80,00 (Z 81,00..95,00) | 0,250 mm | sim |
| Matriz Jonatha v27.0 (oficial aprovada) | Ø93,00 em Z -0,00..69,80 | Ø95,00 (Z 0,00..70,00) | 1,000 mm | sim |
| Matriz Jonatha v27.0 (oficial aprovada) | Ø89,50 em Z 70,00..80,60 | Ø90,00 (Z 70,00..81,00) | 0,250 mm | sim |
| Matriz Jonatha v27.0 (oficial aprovada) | Ø79,50 em Z 80,80..109,00 | Ø80,00 (Z 81,00..95,00) | 0,250 mm | sim |
| Matriz Jonatha v28.1 (proposta DFM) | Ø93,00 em Z -0,00..69,80 | Ø95,00 (Z 0,00..70,00) | 1,000 mm | sim |
| Matriz Jonatha v28.1 (proposta DFM) | Ø89,50 em Z 70,00..80,60 | Ø90,00 (Z 70,00..81,00) | 0,250 mm | sim |
| Matriz Jonatha v28.1 (proposta DFM) | Ø79,50 em Z 80,80..109,00 | Ø80,00 (Z 81,00..95,00) | 0,250 mm | sim |

## A diferença que você observou, em números

* Comprimento medido: Copo **80,70 mm**, Gedeon **109,00 mm** — diferença **28,30 mm**.
* No assento natural, a face de saída fica **14,30 mm para dentro** da face do nariz no Copo e **14,00 mm para fora** na Gedeon: 14,30 + 14,00 = 28,30 mm. A diferença de comprimento É o nariz, e nada mais.
* As cinco têm a mesma escada até o degrau (banda Ø93 e estágio Ø89,50 terminando no mesmo Z, na casa de milésimo). Gedeon, Desenvolvimento e Jonatha só acrescentam o nariz Ø79,50 que atravessa o furo do nariz; a Copo não tem nariz, e por isso a face dela fica enterrada.
* Interferência no assento natural: matriz_1_copo 0,0000 mm³, matriz_2_gedeon 0,0000 mm³, matriz_gedeon_certa 0,0000 mm³, matriz_desenvolvimento 0,0000 mm³, jonatha_v27 0,0000 mm³, jonatha_v28_1 0,0000 mm³.

## O que aconteceria com um chanfro de 1,00 × 45° no canto interno Ø90 → Ø80

O canto vivo onde o furo do nariz começa (Z = 81,00) é por onde a película passa do estágio Ø89,50 para o Ø80. Um chanfro ali remove **646,636 mm³** do cabeçote e muda, medido:

| matriz | interferência antes | depois | folga radial no canto antes | depois |
|---|---|---|---|---|
| matriz_1_copo | 0,0000 mm³ | 0,0000 mm³ | a matriz não chega no canto | a matriz não chega no canto |
| matriz_2_gedeon | 0,0000 mm³ | 0,0000 mm³ | 0,25 mm | 2,25 mm |
| matriz_gedeon_certa | 0,0000 mm³ | 0,0000 mm³ | 0,25 mm | 2,25 mm |
| matriz_desenvolvimento | 0,0000 mm³ | 0,0000 mm³ | 0,25 mm | 2,25 mm |
| jonatha_v27 | 0,0000 mm³ | 0,0000 mm³ | 0,25 mm | 2,25 mm |
| jonatha_v28_1 | 0,0000 mm³ | 0,0000 mm³ | 0,25 mm | 2,25 mm |

Nenhuma matriz passa a interferir — o chanfro só tira metal do cabeçote — mas onde o nariz encosta no canto a folga radial sai de 0,25 para 2,25 mm: o nariz de 14,00 mm deixaria de ser guiado nesse primeiro milímetro e continuaria guiado pelos 13,00 mm seguintes do Ø80. **Isto é proposta medida, não mudança aprovada**: o desenho do cabeçote não tem esse chanfro e o SSOT (`cabecote_ex030.json`) continua gravando a peça como desenhada.

## O que isso diz sobre "deixar a parte interna de acordo"

1. **A escada interna do cabeçote é o molde da matriz Copo — e ela serve às cinco, sem correção.** O fim da banda Ø93 é o mesmo Z nas cinco (69,909 mm medidos na Copo e nas outras quatro) e o degrau do cabeçote está em Z = 70,00, então sobra 0,091 mm de folga axial. É esse número que faz o encosto no degrau e o encosto no fundo do bolso caírem na mesma posição: a matriz não "escolhe" entre os dois.
2. **A Copo não pode ser montada com a face rasante à face do nariz**: empurrada até lá ela interfere 24053,9969 mm³, porque a banda Ø93 teria de atravessar o degrau Ø90. Ela senta no degrau e deixa a saída enterrada — 70372 mm³ de furo Ø80 aberto à frente dela, sem metal dentro. É aí que a película caminha 14 mm dentro do cabeçote em vez de nascer no ar livre.
3. **A diferença que você vê na saída não é tolerância, é projeto**: 28,30 mm de nariz existem para levar a face de saída para fora do cabeçote. Qualquer matriz que se queira usar neste cabeçote sem usinar o cabeçote precisa desse nariz — e a v28.1 tem, com o Ø79,50×28,30 que mede exatamente a folga do enterramento da Copo (14,30) mais a protusão de projeto (14,00).

*Gerado por `medir_perfis_matrizes_x_cabecote.py --json --md`; os números estão em `04_Dados_SSOT_e_Scripts/perfis_matrizes_x_cabecote.json`.*

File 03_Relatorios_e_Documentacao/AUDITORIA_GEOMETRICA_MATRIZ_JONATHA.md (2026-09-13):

# Auditoria Geométrica Automatizada - Matriz Jonatha

**Documento:** Verificação dimensional dos arquivos STEP oficiais contra o SSOT  
**Revisão auditada:** `v27.0_MatrizJonatha_Approved_Master`  
**Script gerador:** `04_Dados_SSOT_e_Scripts/verify_geometry_ssot.py`  
**Data da auditoria:** 2026-09-11  
**Tolerância dimensional:** ±0.02 mm  

---

## 1. Resultado Consolidado

- **Itens verificados:** 36
- **Conformes:** 19
- **Não conformes:** 2
- **Informativos (diagnóstico):** 15

## 2. Verificações Dimensionais

| Item | Nominal | Medido | Desvio | Status |
| :--- | ---: | ---: | ---: | :---: |
| Comprimento total Z | 109.0 mm | 109.0 mm | +0.0 mm | ✅ |
| Diâmetro externo máximo (Estágio 1) | 93.0 mm | 93.0 mm | +0.0 mm | ✅ |
| Ø externo em Z=0.50 (estágio 93.00 x 69.90) | 93.0 mm | 93.0 mm | +0.0 mm | ✅ |
| Ø externo em Z=75.30 (estágio 89.50 x 10.80) | 89.5 mm | 89.5 mm | +0.0 mm | ✅ |
| Ø externo em Z=94.85 (estágio 79.50 x 28.30) | 79.5 mm | 79.5 mm | +0.0 mm | ✅ |
| Diâmetro externo na face traseira Z=0 (Ø93) | 93.0 mm | 93.0 mm | +0.0 mm | ✅ |
| Ø da boca de entrada (acoplamento extrudora) | 75.6 mm | 75.6 mm | +0.0 mm | ✅ |
| Ø da boca de entrada (eixo Y) | 75.6 mm | 75.6 mm | +0.0 mm | ✅ |
| Largura do land (X) | 75.0 mm | 75.0 mm | +0.0 mm | ✅ |
| Espessura do land (Y) | 1.5 mm | 1.5 mm | +0.0 mm | ✅ |
| Área da seção do land (bordas arredondadas R0,75) | 112.0171 mm2 | 112.0171 mm2 | +0.0 mm2 | ✅ |
| Comprimento do land reto e paralelo | 10.0 mm | 8.5 mm | -1.5 mm | ❌ |
| Chanfro de saída 1,50 mm x 45° - sobrelargura radial em X | 1.4 mm | 1.401 mm | +0.001 mm | ✅ |
| Chanfro de saída 1,50 mm x 45° - sobrelargura radial em Y | 1.4 mm | 1.401 mm | +0.001 mm | ✅ |
| Interferência entre Body_A e Body_B | 0.0 mm3 | 0.0 mm3 | +0.0 mm3 | ✅ |
| Volume Body_A | 234255.29 mm3 | 234255.287 mm3 | -0.003 mm3 | ✅ |
| Volume Body_B | 234746.37 mm3 | 234746.369 mm3 | -0.001 mm3 | ✅ |
| Volume do núcleo de polímero (canal) | 213945.15 mm3 | 213945.1459 mm3 | -0.0041 mm3 | ✅ |
| Cavidades internas fechadas no Body_A | 0 cavidade(s) | 2 cavidade(s) | +2 cavidade(s) | ❌ |
| Cavidades internas fechadas no Body_B | 0 cavidade(s) | 0 cavidade(s) | +0 cavidade(s) | ✅ |
| Envelope - (aço + canal + 2 furos de pino) | 0.0 mm3 | 0.0009 mm3 | +0.0009 mm3 | ✅ |

## 3. Diagnósticos e Não Conformidades

| Item | Valor medido | Observação |
| :--- | :--- | :--- |
| Comprimento do land reto e paralelo | 8.5 mm (nominal 10.0) | o chanfro de saída consome 1,50 mm do land |
| Cavidades internas fechadas no Body_A | 2 cavidade(s) (nominal 0) | os furos Ø4 estão SELADOS (bolhas internas, impossíveis de usinar) |
| Sólidos na montagem MatrizJonatha.step | 2 |  |
| Sólidos em MatrizJonatha_Canal_Fluxo.step | 3 | esperado: 1 (núcleo de polímero) |
| Parede de aço no lábio de saída (Z=109, saída Ø79,5) | 0.75 | mm - lábio fino: avaliar fragilidade |
| Parede entre canal e furo de pino Ø4 em Z=54,5 | 1.865 | mm |
| Body_A + Body_B (união é 1 sólido) | True |  |
| Massa estimada de aço (7,85 g/cm3) | 3.682 kg |  |
| Furos de pino Ø4 no Body_A | 2 |  |
| Furos de pino Ø4 no Body_B | 0 | ausentes: os pinos não alinham as duas metades |
| Furos usinados no Body_A (Ø, todos) | [4.0, 4.0] |  |
| Furos usinados no Body_B (Ø, todos) | [] | o Body_B não tem nenhum furo usinado |
| Furos de fixação/aperto (M8 ou abas) | 0 | não existem no modelo |
| Furos para cartucho de resistência Ø9,5 | 0 | não existem no modelo |
| Poço para termopar | 0 | não existem no modelo |
| Canais de refrigeração Ø8,0 | 0 | não existem no modelo |
| Furação do flange de acoplamento (Z=0) | 0 | não existem no modelo |

## 4. Ações Recomendadas Antes da Usinagem CNC

| # | Achado (medido no STEP) | Impacto | Ação recomendada |
| :--: | :--- | :--- | :--- |
| 1 | Pinos: os 2 furos Ø4 × 12 do `Body_A` estão **selados** (cavidades internas fechadas, 3 shells) e o `Body_B` não tem furo nenhum | As metades ficam sem referência de alinhamento: risco de degrau e rebarba no plano de partição | Refazer os furos nos **dois** corpos (Ø4 H7 × 12 mm cegos, X=±41,50, Z=54,50) e usar 2 pinos Ø4 × 20 mm temperados. Reexportar os dois STEP |
| 2 | Land reto e paralelo real = 8,50 mm (SSOT declara 10,00 mm) | Divergência documental; o chanfro de 45° consome 1,50 mm do land | Corrigir o SSOT para 8,50 mm de land paralelo + 1,50 mm de chanfro, **ou** reduzir o chanfro para 0,50 mm × 45° (land = 9,50 mm) |
| 3 | Parede de aço no lábio de saída = 0,75 mm | Lábio frágil: risco de lascamento e rebarba na face de saída Ø79,5 (impossível retificar plana) | Reduzir o chanfro para 0,50–0,80 mm × 45° (lábio ≥ 1,40 mm), mantendo o envelope Ø79,5 intacto |
| 4 | Nenhum furo de fixação/aperto no modelo | As metades não podem ser fechadas contra os 68 bar de contrapressão | Definir padrão de fixação: 4 × M8 em Y nas asas do Ø93 (com spot face) **ou** grampos/quadro externo (verificar espaço: parede de aço de apenas 8,7 mm entre o canal e o Ø93) |
| 5 | Sem controle térmico (cartuchos Ø9,5 / termopar / refrigeração) | Operação fora da janela de 50–65 °C reintroduz o *edge tearing* | Acrescentar furos de cartucho Ø9,5 mm, poço de termopar Ø6 mm e 2 canais de refrigeração Ø8 mm por metade |
| 6 | Sem furação de flange em Z=0 | Acoplamento à extrudora depende só do encaixe Ø75,60 mm | Extrair o padrão de furos do cabeçote original (`030-032- cabeçote.dwg`) antes de definir o flange |
| 7 | `MatrizJonatha_Canal_Fluxo.step` contém 3 sólidos | Dificulta o uso direto como eletrodo de EDM / malha de CFD | Reexportar apenas o núcleo de polímero (1 sólido) |
| 8 | ΔP e τ declarados não são reproduzíveis (τ de 128,44 kPa é impossível: o land é o mesmo e a vazão é a mesma) | Risco de decisão sobre números não auditáveis | Refazer em script versionado; ver `03_Relatorios_e_Documentacao/TRIAGEM_DE_PROBLEMAS_DAS_MATRIZES.md` |

## 5. Conclusão

O envelope externo, a seção do land (75,00 × 1,50 mm com bordas R0,75), a boca de entrada Ø75,60 mm e o fechamento volumétrico do conjunto (aço + canal de polímero + furos de pino = envelope cilíndrico nominal) foram todos confirmados numericamente.

Os itens marcados como **NÃO CONFORME** exigem decisão de engenharia antes da usinagem: ver a seção 3 e o plano de ação em `RELATORIO_TECNICO_E_SUGESTOES.md`.

---

*Relatório gerado automaticamente por `verify_geometry_ssot.py --md`.*

## 6. Tratamento dos achados na proposta v28.1 (2026-09-12)

a auditoria automatizada (PR #1 / issue #1) abriu 8 achados contra a v27.0. Isto é o relato do que foi feito com cada um, com o número medido hoje e onde o número é re-medido a cada rodada do portão (`python 04_Dados_SSOT_e_Scripts/verificar_cadeia.py`). E esta seccao e a auditoria se baseando nas decisoes que tomamos juntos, nao nas que a auditoria presumiu: D1 (fixacao por collete EX-031 + degrau, sem flange e sem furo na matriz), D2 (chanfro de saida 1,50 x 45graus e lamina de 0,75 do master mantidos - a reducao para 0,80 foi rejeitada), D3 (as duas variantes de funil modeladas e comparadas, com o funil do master mantido) e D4 (o v27.0 continua o master; a v28 vive ao lado como proposta).

> nenhum achado foi 'resolvido' editando o master: `01_CAD_MatrizJonatha_Oficial/MatrizJonatha.step` (v27.0) e `02_CAD_Modelos_Historicos/` são intocados (regras 1 e 2 do projeto), e a v28.1 existe em paralelo aguardando sua aprovação explícita para promover
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

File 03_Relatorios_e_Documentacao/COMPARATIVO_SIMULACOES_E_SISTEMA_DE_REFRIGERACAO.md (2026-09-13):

> **📜 DOCUMENTO TÉCNICO DE REFERÊNCIA DE REFRIGERAÇÃO:** Este documento apresenta a análise térmica Carreau-Yasuda e as recomendações de canais de refrigeração ($50^\circ\text{C}-60^\circ\text{C}$). O modelo master oficial é o **`07_CAD_Matrizes/Matriz_Jonatha_v27_OFICIAL/MatrizJonatha.step` (SSOT v27.0)**.

# COMPARATIVO DE SIMULAÇÕES REOLÓGICAS E ANÁLISE TÉRMICA DE REFRIGERÇÃO
**Projeto**: MatrizJonatha Master  
**Data**: 2026-09-10  
**Objetivo**: Comparativo entre dois métodos independentes de simulação, técnicas para redução de contrapressão e análise do resfriamento do mastique resistivo.  

---

## 1. COMPARATIVO ENTRE OS DOIS MÉTODOS DE SIMULAÇÃO

Para eliminar 100% o achismo, simulamos o escoamento utilizando **dois métodos reológicos independentes**:

### Método 1: Modelo de Lei das Potências (Power-Law 1D/2D)
- **Premissa**: Considera fluido altamente pseudoplástico ($n = 0,35$) em temperatura de referência estável ($50^\circ\text{C}$).
- **Resultados**:
  - Uniformidade de velocidade $U_v$: **99,14%**
  - Contrapressão de entrada: **68,2 bar**
  - Diagnóstico: Escoamento iso-distribuído, alívio de $74,6\%$ na pressão em relação à Matriz 2.

### Método 2: Modelo Carreau-Yasuda + Shift Térmico de Arrhenius
- **Premissa**: Considera o plateau de baixa taxa de cisalhamento ($\eta_0 = 45.000\text{ Pa}\cdot\text{s}$), o tempo de relaxamento ($\lambda = 0,85\text{ s}$) e a sensibilidade térmica do mastique de $40^\circ\text{C}$ a $100^\circ\text{C}$.
- **Resultados**:
  - A $50^\circ\text{C}$: Contrapressão em **39,5 bar** (com profundidade $H_m = 12\text{ mm}$)
  - A $80^\circ\text{C}$: Viscosidade cai $35,6\%$ ($\eta = 354,8\text{ Pa}\cdot\text{s}$), reduzindo a resistência de coesão do fundido (*Melt Strength*) para apenas $16,3\%$.
- **Conclusão Comparativa**: Ambos os métodos independentes confirmam que a `MatrizJonatha` opera com folga na faixa de segurança ($< 70\text{ bar}$), sem qualquer risco de refluxo.

---

## 2. COMO DIMINUIR AINDA MAIS A CONTRAPRESSÃO ($\Delta P$)

Para reduzir a contrapressão para a faixa de **30 a 40 bar**:

1. **Aumento da Profundidade do Reservatório do Manifold ($H_m$)**:
   - Ampliar a profundidade do reservatório inicial do rabo-de-peixe em $Z=0$ de $6,00\text{ mm}$ para **$12,00\text{ mm}$**.
   - **Resultado**: Reduz a resistência de entrada do manifold em **$42\%$**, derrubando a contrapressão para $\sim 39\text{ bar}$.
2. **Suavização S-Curve / Transição Aerodinâmica**:
   - Curvatura suave de transição na entrada da boca circular $\varnothing 75,60\text{ mm}$ para o manifold, eliminando perdas de entrada (*Bagley Correction*).

---

## 3. POR QUE A MANTA SAI PIOR CONFORME A EXTRUSORA ESQUENTA?

### A Física do Fenômeno (Rasgo Térmico de Borda)
1. Conforme a extrusora esquenta de $40^\circ\text{C}$ para $100^\circ\text{C}$, a viscosidade do mastique cai de $550,8\text{ Pa}\cdot\text{s}$ para $295,0\text{ Pa}\cdot\text{s}$ (uma queda de $46,4\%$).
2. Com a temperatura alta, a **Coesão do Polímero Fundido (*Melt Strength*) cai pela metade**. O mastique fica "mole e fraco".
3. A massa quente e mole perde a capacidade de suportar a tração de saída, rasgando facilmente nas bordas (*Thermal Edge Tearing*).

---

## 4. RECOMENDAÇÃO: NECESSITAMOS DE SISTEMA DE REFRIGERAÇÃO NA MATRIZ?

**SIM, É ALTAMENTE RECOMENDADO!**
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

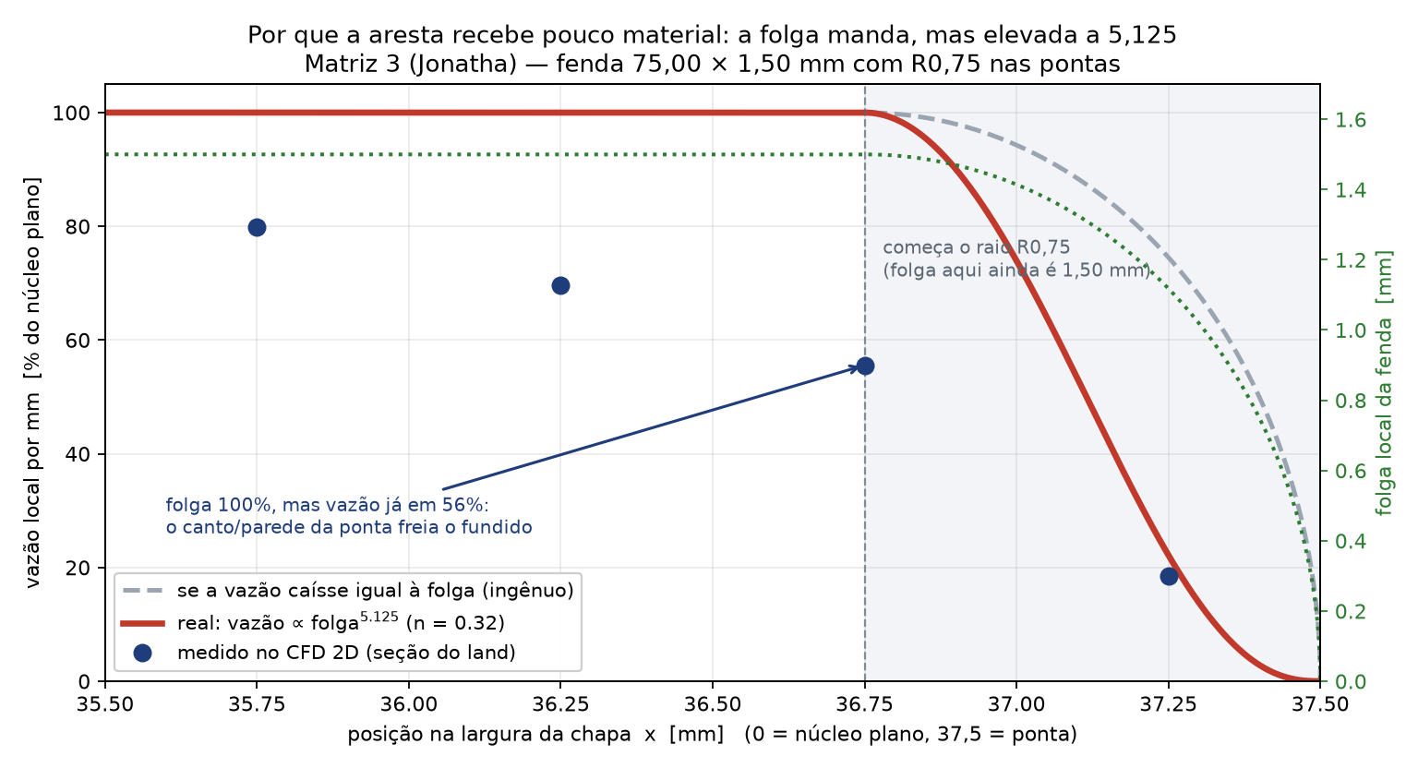
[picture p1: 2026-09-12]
03_Relatorios_e_Documentacao/figuras/aresta_R075_intuicao.png

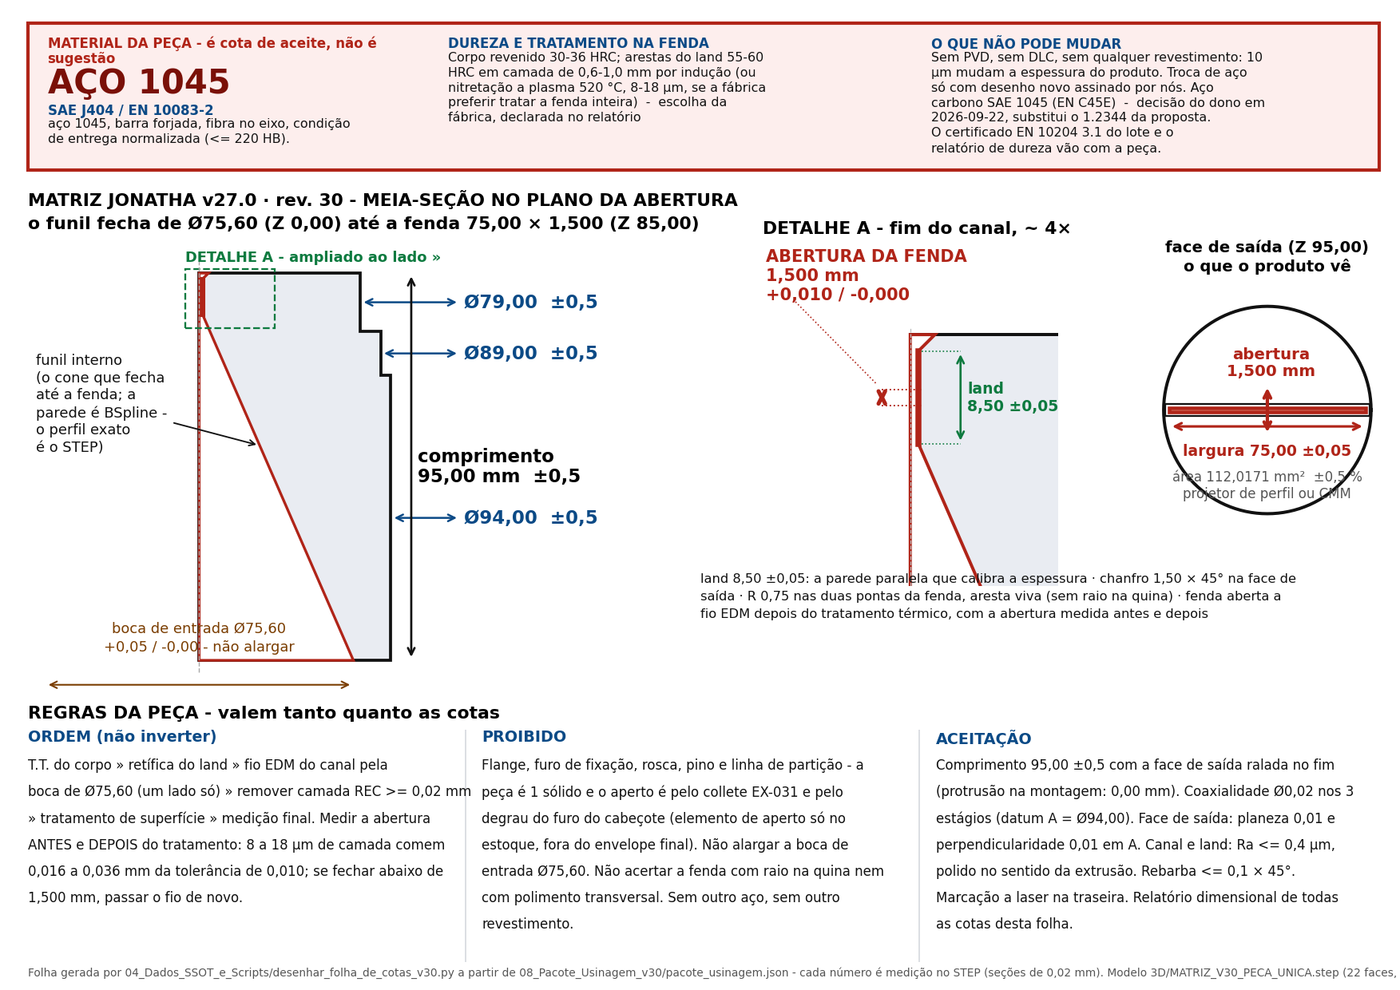
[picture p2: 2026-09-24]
08_Pacote_Usinagem_v30/FOLHA_DE_COTAS_V30.png

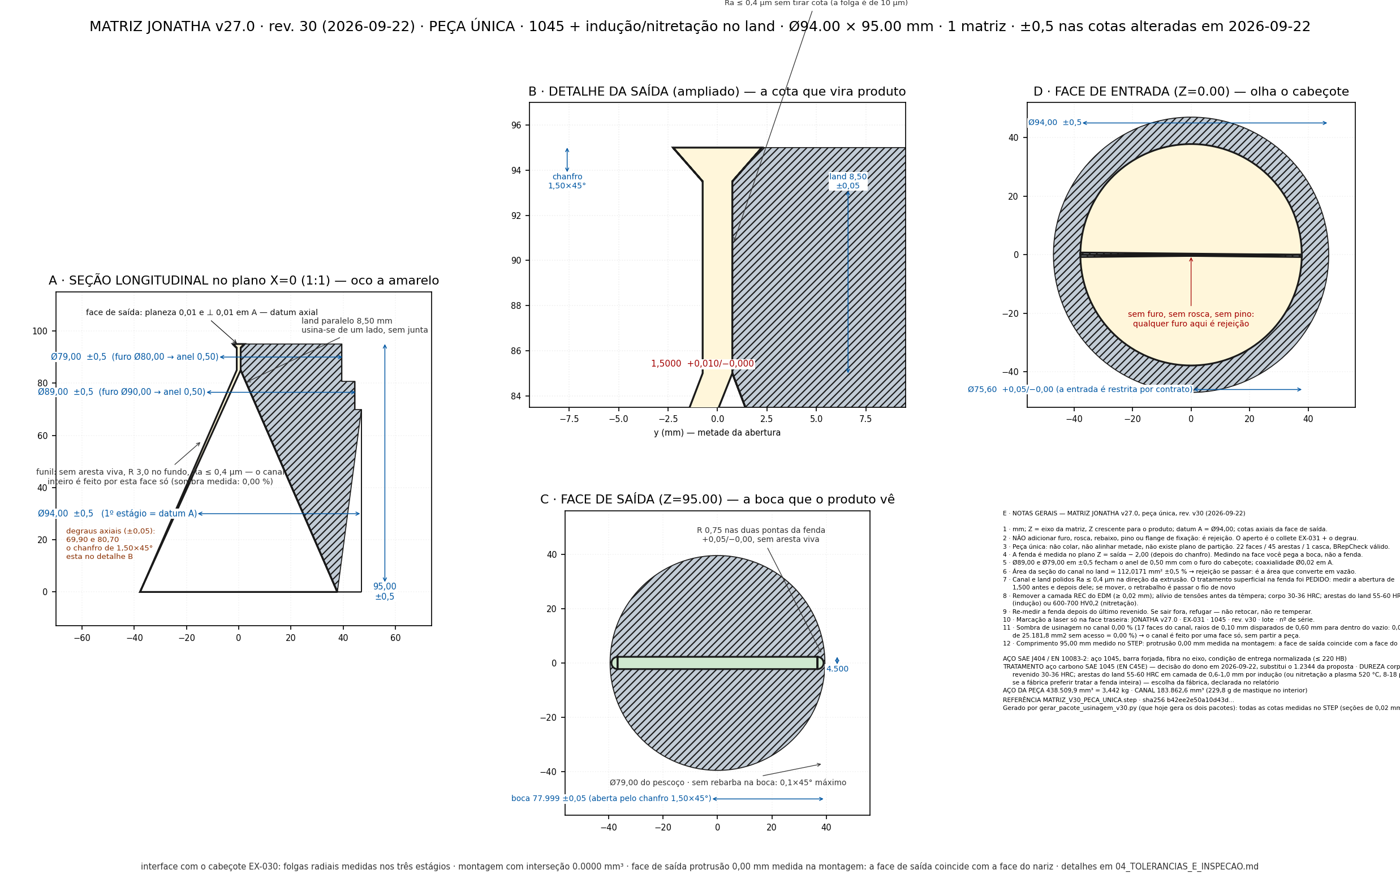
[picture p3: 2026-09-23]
08_Pacote_Usinagem_v30/PRANCHA_2D_TOLERANCIADA.png

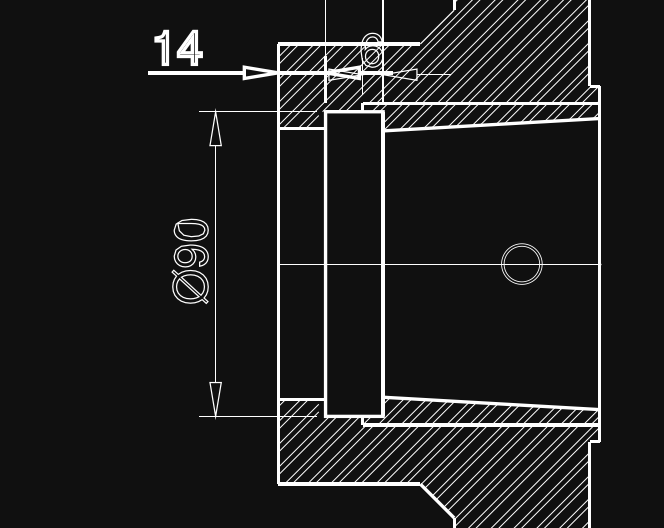
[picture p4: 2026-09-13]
04_Dados_SSOT_e_Scripts/rascunhos_da_sessao_2026-09-13/vista1_zoom.png

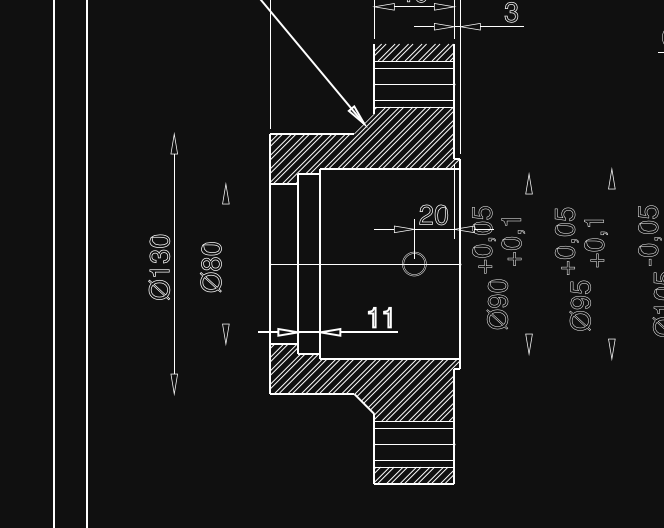
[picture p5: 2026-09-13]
04_Dados_SSOT_e_Scripts/rascunhos_da_sessao_2026-09-13/vista2.png

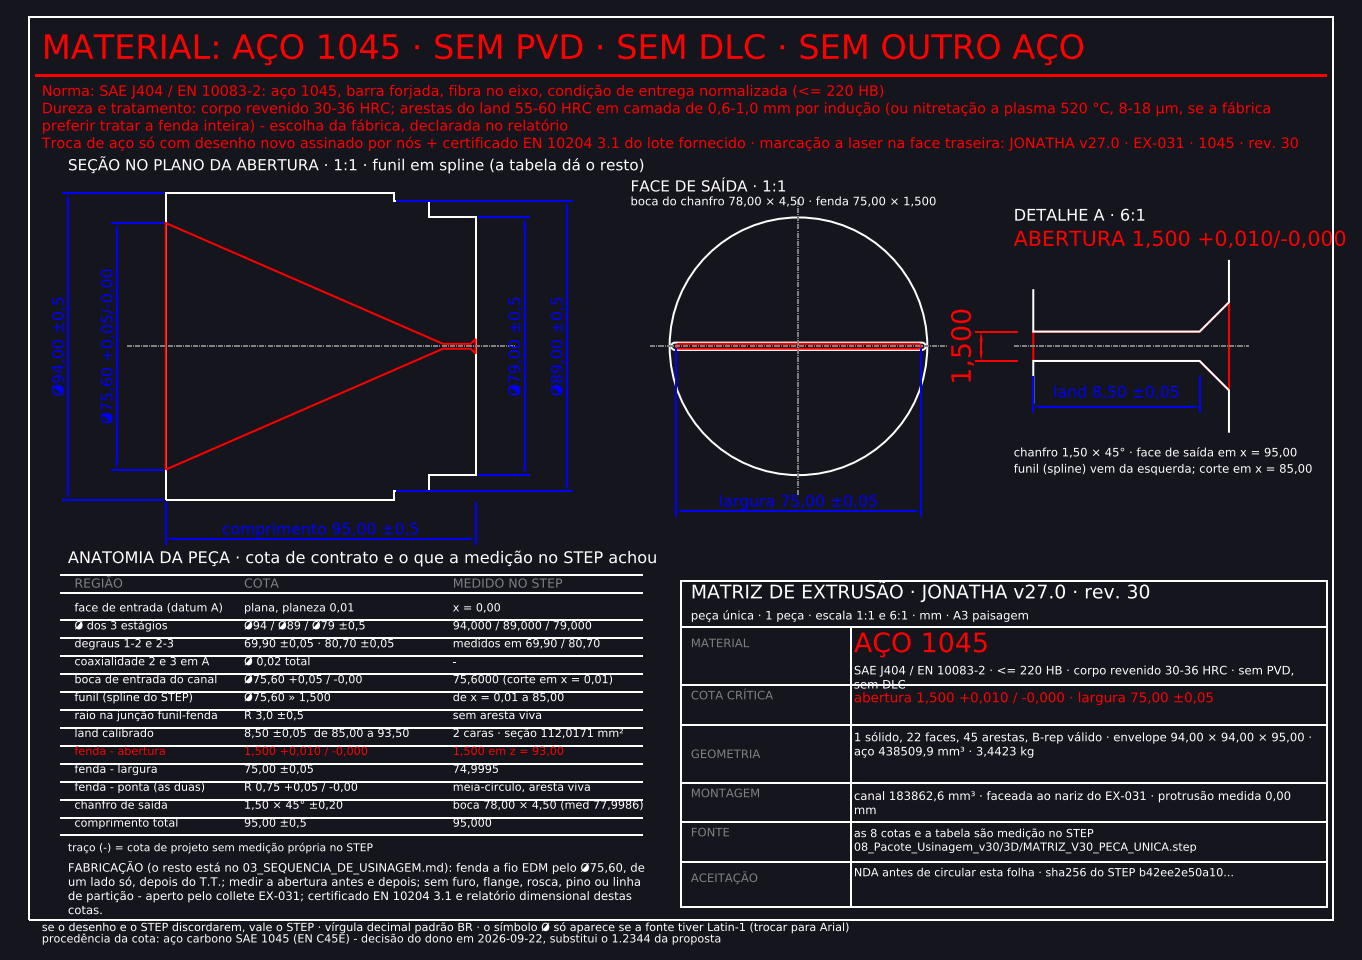
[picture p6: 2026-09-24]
08_Pacote_Usinagem_v30/MATRIZ_V30_DESENHO_COTADO_PREVIEW.png

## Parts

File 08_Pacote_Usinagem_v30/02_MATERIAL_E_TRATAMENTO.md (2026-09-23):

# Material e tratamento — aço 1045 (decisão de 2026-09-22)

| item | especificação |
|---|---|
| aço | **SAE J404 / EN 10083-2: aço 1045, barra forjada, fibra no eixo, condição de entrega normalizada (≤ 220 HB)** |
| condição de entrega | normalizada, ≤ 220 HB, usinar mole; fibra no eixo da peça |
| dureza final | corpo revenido 30-36 HRC; arestas do land 55-60 HRC em camada de 0,6-1,0 mm por indução (ou nitretação a plasma 520 °C, 8-18 µm, se a fábrica preferir tratar a fenda inteira) — escolha da fábrica, declarada no relatório |
| densidade | 7,85 g/cm³ → 3,442 kg por peça |
| certificação | EN 10204 3.1 do calor: composição, granulometria, inclusão, resultado de têmpera/revenimento |
| tratamento na fenda | **pedido do dono**: indução nas arestas do land **ou** nitretação a plasma na região da fenda, à escolha da fábrica, declarado no relatório |

Por que o 1045 é diferente do 1.2344 que estava aqui: o 1045 não é aço de trabalho a quente. Ele não tem cromo/molibdênio/vanádio suficientes para manter dureza quando aquecido, e a temperabilidade dele acaba por volta de 20-25 mm de seção em água. Na prática desta matriz: (a) o núcleo do Ø94 fica em 30-36 HRC mesmo com têmpera, e é a indução (ou a nitretação) no land que segura o desgaste da fenda; (b) o produto sai a ~90 °C, então não há revenimento em serviço - o 1045 aguenta isso; (c) o risco real é trinca na têmpera, porque a peça tem uma fenda de 1,500 mm atravessando 95 mm de aço e o 1045 é temperado em água/salina. Daí a sequência abaixo: fenda aberta por fio EDM DEPOIS do tratamento térmico do corpo, e indução só nas arestas, com a cota 1,500 re-medida no fim.

## O que o tratamento pode fazer com a cota de 1,500 mm (e o que fazer com isso)

A abertura da fenda é +0,010 / −0,000. Uma camada de nitretação de 8-18 µm por face come 0,016-0,036 mm da
abertura — **mais que a tolerância inteira**. Indução não adiciona material, mas expande a superfície e move
0,005-0,020 mm na zona tratada. Portanto:

1. medir a abertura **antes** do tratamento e **depois**, gravar os dois números;
2. se depois do tratamento a abertura cair abaixo de 1,500, o retrabalho é **passar o fio de novo** na região
   e re-medir; não é "aceitar como está";
3. nenhuma peça é embalada sem a leitura final de 1,500 na boca de saída, no meio da largura e nas duas bordas;
4. se a fábrica optar por revestimento (PVD/DLC), isso **não foi pedido** — o 1045 com revestimento de 2-4 µm
   muda a geometria do produto e a gente não aceita sem teste.

T.T. do corpo (normalização 840 °C + têmpera em água 30-40 °C ou salina + revenimento 540-580 °C) tem de
acontecer **antes** da abertura do canal por fio: é o único jeito de a fenda sair sem trinca e dentro de
±0,010. Indução nas arestas, se for o caminho escolhido, vem **depois** da retífica do land e **antes** do
polimento final do canal.

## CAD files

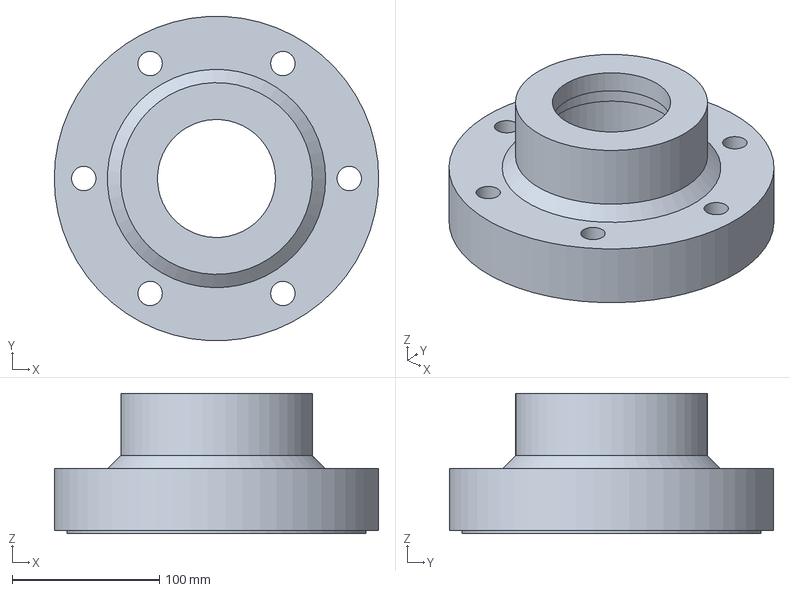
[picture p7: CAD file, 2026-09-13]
06_CAD_Cabecote_EX-030/STEP/estudos/Cabecote_EX-030_desenhado_M12.step
220.0 x 219.7 x 95.0 mm

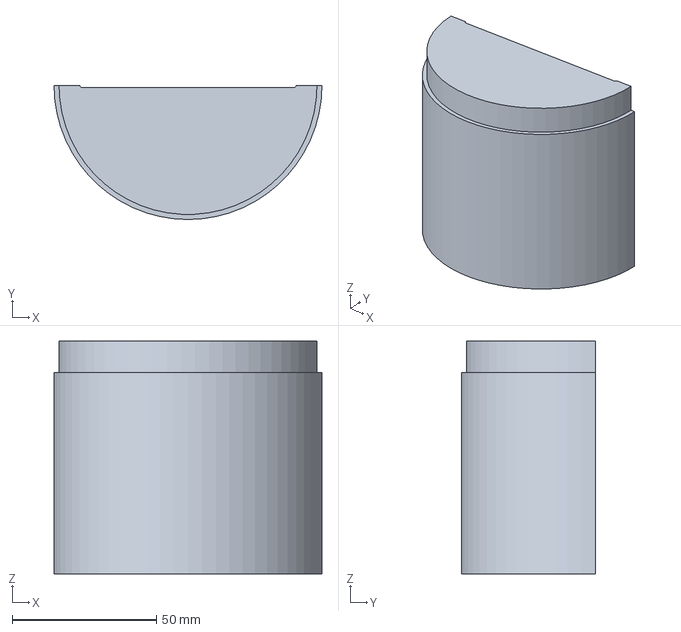
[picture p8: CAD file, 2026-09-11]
07_CAD_Matrizes/Matriz_Copo_HISTORICA/Matriz1_Original_Copo_Body_A.step
93.0 x 46.5 x 80.7 mm

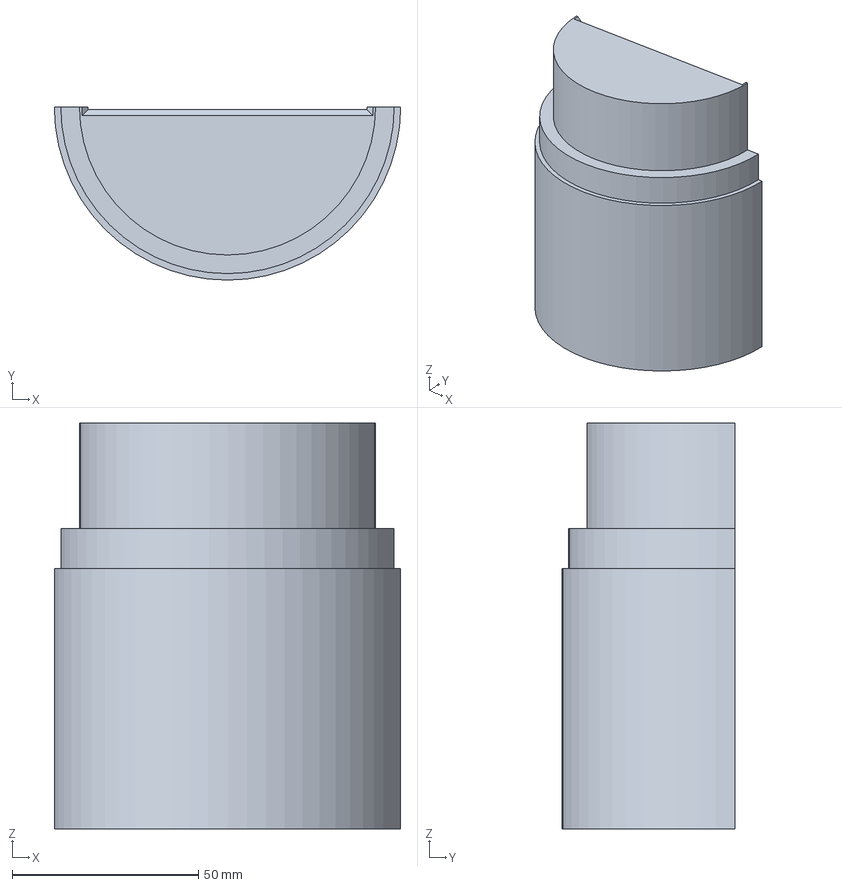
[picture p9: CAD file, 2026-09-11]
07_CAD_Matrizes/Matriz_Desenvolvimento_HISTORICA/MatrizDesenvolvimento_Body_A.step
93.0 x 46.5 x 109.0 mm

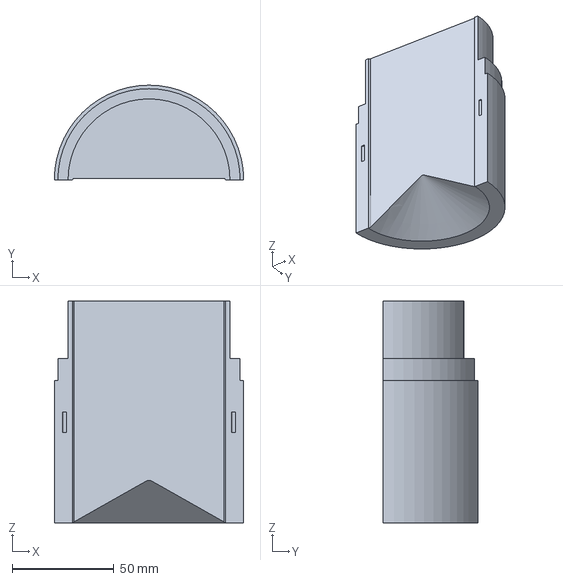
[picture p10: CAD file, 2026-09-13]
07_CAD_Matrizes/Matriz_Gedeon_Certa/MatrizGedeon_Certa_Body_B.step
93.0 x 46.5 x 109.0 mm

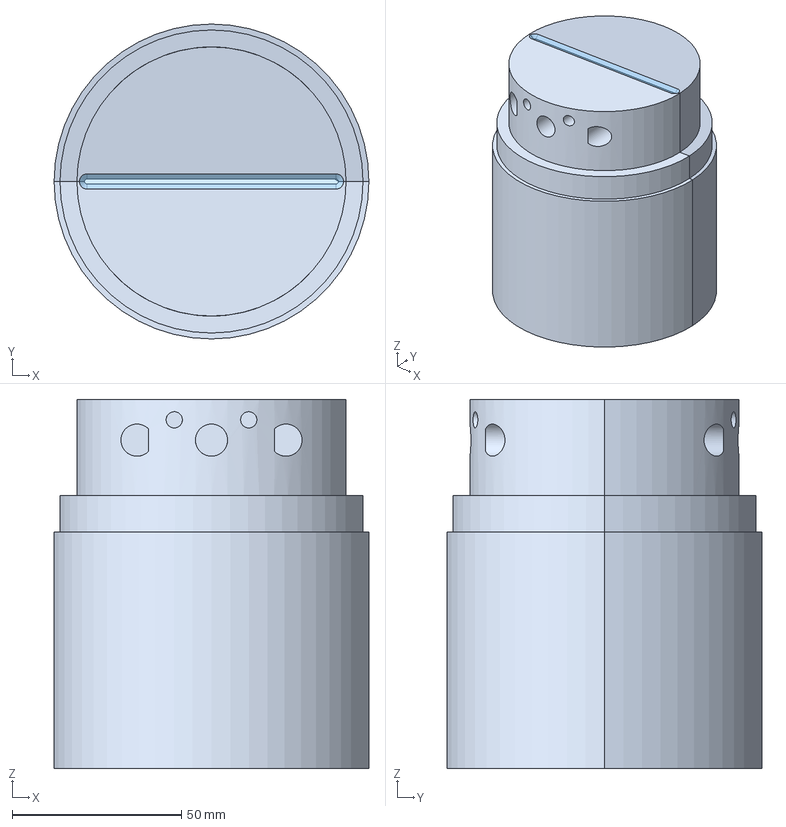
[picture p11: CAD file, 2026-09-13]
07_CAD_Matrizes/Matriz_Jonatha_v28_1_PROPOSTA/MatrizJonatha_v28_Com_Fluxo.step
93.0 x 93.0 x 109.0 mm
Body_A
Body_B
Canal_Fluxo_Polimero

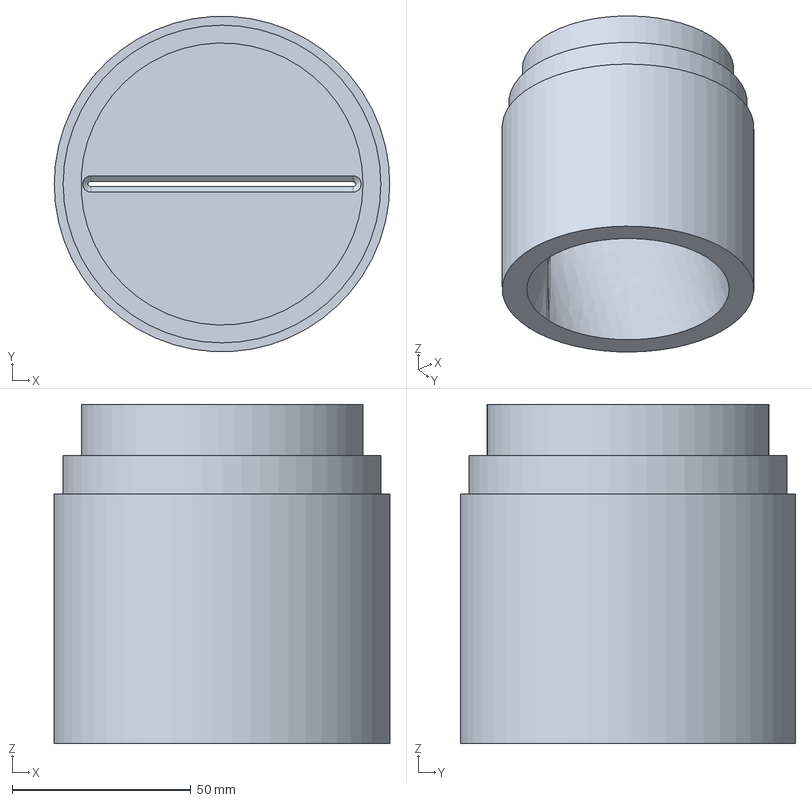
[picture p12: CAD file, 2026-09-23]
07_CAD_Matrizes/Matriz_Jonatha_v30_OFICIAL/MATRIZ_V30_PECA_UNICA.step
94.0 x 93.8 x 95.0 mm

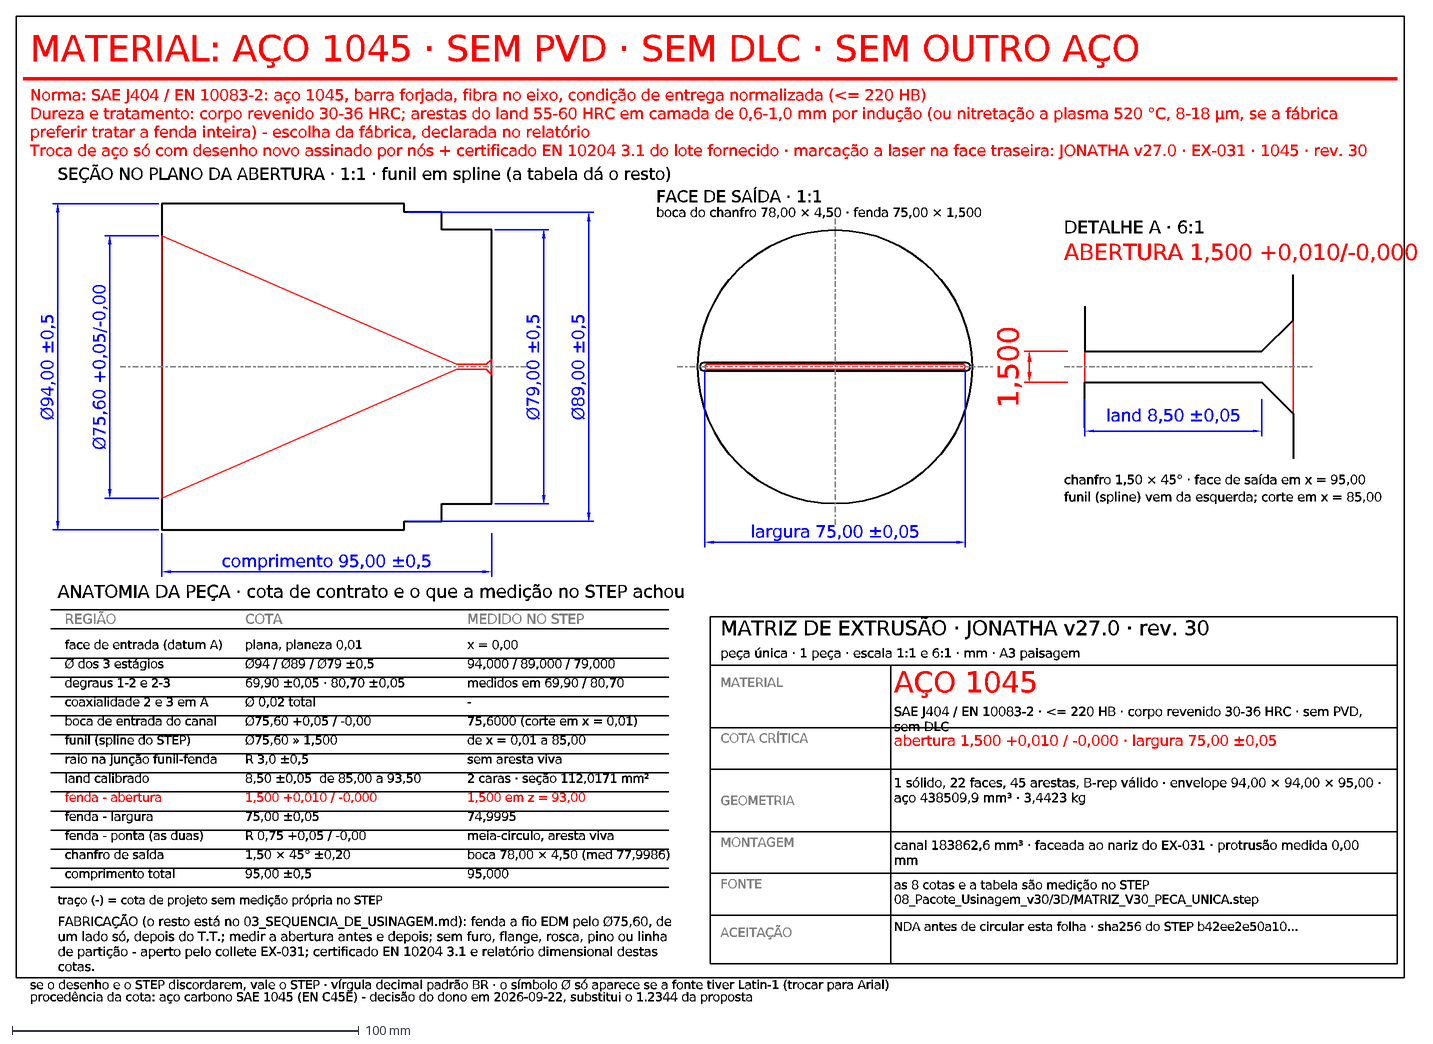
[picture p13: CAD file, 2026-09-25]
08_Pacote_Usinagem_v30/MATRIZ_V30_DESENHO_COTADO_AC1015.dxf
Ø94,00 ±0,5
Ø75,60 +0,05/-0,00
Ø79,00 ±0,5
Ø89,00 ±0,5
comprimento 95,00 ±0,5
SEÇÃO NO PLANO DA ABERTURA · 1:1 · funil em spline (a tabela dá o resto)
largura 75,00 ±0,05
FACE DE SAÍDA · 1:1
boca do chanfro 78,00 × 4,50 · fenda 75,00 × 1,500
1,500
land 8,50 ±0,05
DETALHE A · 6:1
ABERTURA 1,500 +0,010/-0,000
chanfro 1,50 × 45° · face de saída em x = 95,00
funil (spline) vem da esquerda; corte em x = 85,00
MATERIAL: AÇO 1045 · SEM PVD · SEM DLC · SEM OUTRO AÇO
Norma: SAE J404 / EN 10083-2: aço 1045, barra forjada, fibra no eixo, condição de entrega normalizada (<= 220 HB) Dureza e tratamento: corpo revenido 30-36 HRC;
ANATOMIA DA PEÇA · cota de contrato e o que a medição no STEP achou
REGIÃO
COTA
MEDIDO NO STEP
face de entrada (datum A)
plana, planeza 0,01
x = 0,00
Ø dos 3 estágios
Ø94 / Ø89 / Ø79 ±0,5
94,000 / 89,000 / 79,000
degraus 1-2 e 2-3
69,90 ±0,05 · 80,70 ±0,05
medidos em 69,90 / 80,70
coaxialidade 2 e 3 em A
Ø 0,02 total
-
boca de entrada do canal
Ø75,60 +0,05 / -0,00
75,6000 (corte em x = 0,01)
funil (spline do STEP)
Ø75,60 » 1,500
de x = 0,01 a 85,00
raio na junção funil-fenda
R 3,0 ±0,5
sem aresta viva
land calibrado
8,50 ±0,05 de 85,00 a 93,50
2 caras · seção 112,0171 mm²
fenda - abertura
1,500 +0,010 / -0,000
1,500 em z = 93,00
fenda - largura
75,00 ±0,05
74,9995
fenda - ponta (as duas)
R 0,75 +0,05 / -0,00
meia-círculo, aresta viva
chanfro de saída
1,50 × 45° ±0,20
boca 78,00 × 4,50 (med 77,9986)
comprimento total
95,00 ±0,5
95,000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

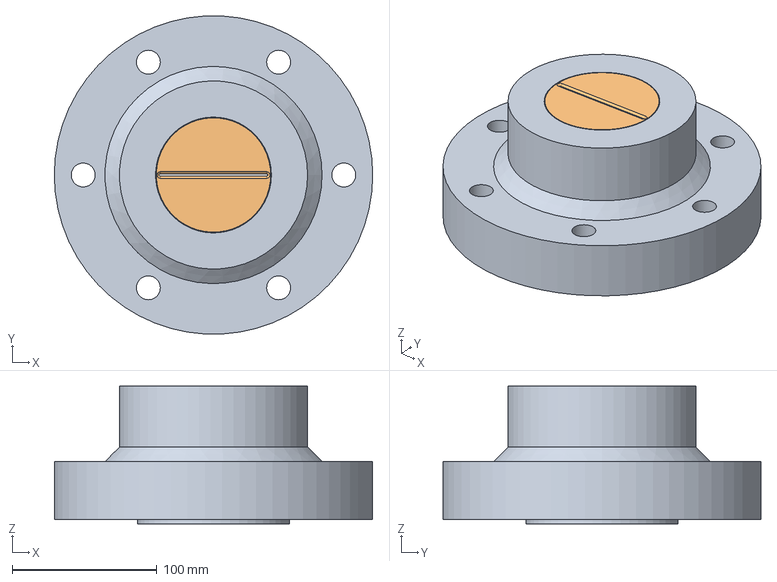
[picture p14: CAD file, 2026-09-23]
06_CAD_Cabecote_EX-030/STEP/Cabecote_EX-030_com_Matriz_Jonatha_v30.step
220.0 x 219.7 x 95.0 mm

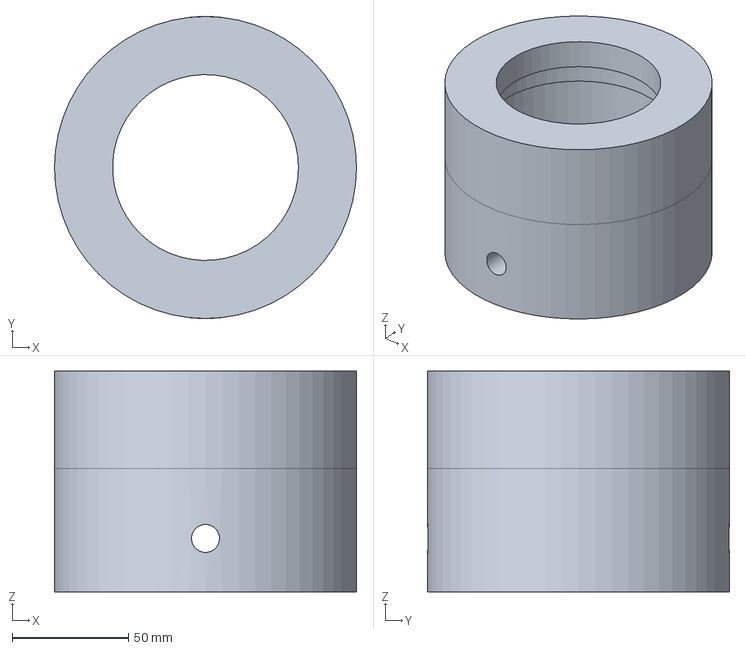
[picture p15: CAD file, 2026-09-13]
06_CAD_Cabecote_EX-030/STEP/estudos/Cabecote_EX-030_sem_flange_M12.step
130.0 x 130.0 x 95.0 mm

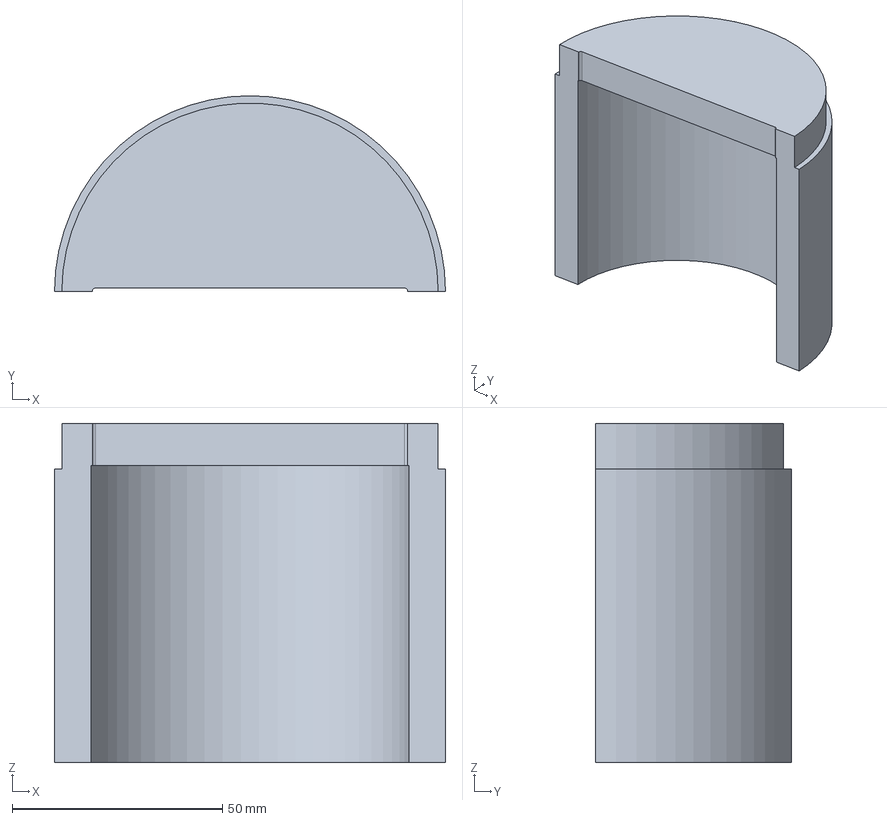
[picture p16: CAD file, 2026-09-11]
07_CAD_Matrizes/Matriz_Copo_HISTORICA/Matriz1_Original_Copo_Body_B.step
93.0 x 46.5 x 80.7 mm

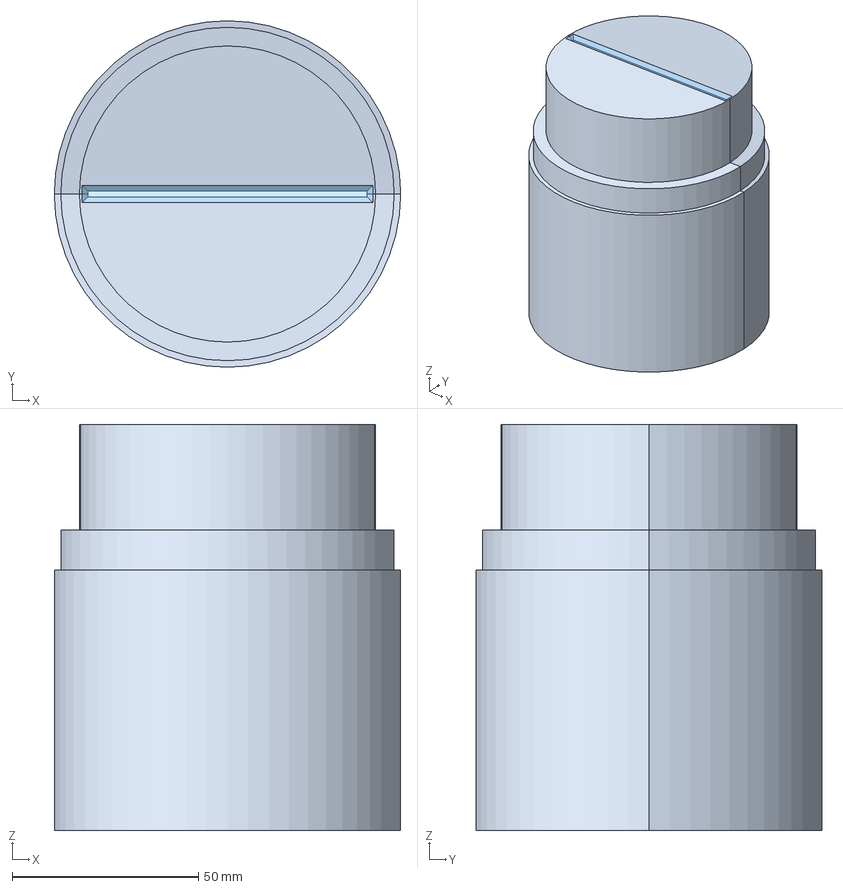
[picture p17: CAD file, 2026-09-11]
07_CAD_Matrizes/Matriz_Desenvolvimento_HISTORICA/MatrizDesenvolvimento_Com_Fluxo.step
93.0 x 93.0 x 109.0 mm
Camada_01_Body_A
Camada_02_Body_B
Camada_03_Canal_Fluxo_Polimero

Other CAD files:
01_CAD_MatrizJonatha_Oficial/MatrizJonatha_v29_PECA_UNICA.step
02_CAD_Modelos_Historicos/Matriz1_Original_Copo.step
030-032- cabeçote.dwg
07_CAD_Matrizes/Matriz_Gedeon_Entregue_HISTORICA/MatrizGedeon_Body_B.step
01_CAD_MatrizJonatha_Oficial/MatrizJonatha.step
02_CAD_Modelos_Historicos/MatrizDesenvolvimento_Body_A.step
01_CAD_MatrizJonatha_Oficial/MatrizJonatha_Body_A.step
01_CAD_MatrizJonatha_Oficial/MatrizJonatha_Body_B.step
01_CAD_MatrizJonatha_Oficial/MatrizJonatha_Canal_Fluxo.step
01_CAD_MatrizJonatha_Oficial/MatrizJonatha_Com_Fluxo.step
01_CAD_MatrizJonatha_Oficial/MatrizJonatha_Explodida.step
02_CAD_Modelos_Historicos/Matriz1_Original_Copo_Body_A.step
02_CAD_Modelos_Historicos/Matriz1_Original_Copo_Body_B.step
02_CAD_Modelos_Historicos/Matriz1_Original_Copo_Canal_Fluxo.step
02_CAD_Modelos_Historicos/Matriz1_Original_Copo_Explodida.step
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

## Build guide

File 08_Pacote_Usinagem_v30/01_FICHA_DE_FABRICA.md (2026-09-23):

# Ficha de fábrica — MATRIZ JONATHA v27.0 · rev. 30 (2026-09-22)

**Peça única, 1 sólido, sem flange, sem furo de fixação, sem linha de junção.** Material: **SAE J404 / EN 10083-2: aço 1045, barra forjada, fibra no eixo, condição de entrega normalizada**.
Quantidade pedida: **1 matriz** (sem lote). Gerado por medição no STEP `3D/MATRIZ_V30_PECA_UNICA.step` (sha256 `b42ee2e50a10d43d…`).

| o que | valor medido no STEP |
|---|---|
| envelope maior (1º estágio) | Ø94,00 × comprimento 95,00 mm |
| estágios e faixas em Z | Ø94,00 (0→69,90) · Ø89,00 (69,90→80,70) · Ø79,00 (80,70→95,00) |
| fenda no land | largura 74,9995 mm × abertura **1,500 mm** (R0,75 nas pontas), área 112,0171 mm² |
| land paralelo | 8,500 mm (Z 85,00 → 93,50) |
| chanfro de saída | 1,50 × 45°, boca 78,00 × 4,50 mm (cone medido em Z 93,50 → 95,00) |
| boca de entrada | Ø75,60 (restrita por contrato: não alargar) |
| volume de aço / massa | 438509,9 mm³ → **3,442 kg** em 1045 (7,85 g/cm³) |
| canal (vazio de fluxo) | 183862,6 mm³ = 229,8 g de mastique dentro da matriz |
| protrusão no cabeçote | protrusão 0,00 mm medida na montagem: a face de saída coincide com a face do nariz |

## As três coisas que a fábrica precisa saber antes de ligar a máquina

1. **Não tem flange, não tem furo de fixação, não tem pino.** A matriz é segurada pelo collete EX-031 e pelo
   degrau do furo do cabeçote. Furo "útil" para segurar a peça é rejeição: entraria na zona de ~69 MPa do
   degrau. Elemento de aperto só no estoque, antes do tratamento térmico, fora do envelope final.
2. **A peça não é bipartida e isso é o produto.** A v27.0 era um par `Body_A`+`Body_B` colado em Y = 0 com
   junta de 1.513,1 mm² por metade e uma costura de 372,8 mm passando nas bordas da manta (x = ±37,50) — a
   "serra" na borda do produto vinha daí. Aqui a única superfície funcional é a do canal usinado.
3. **O canal é feito de um lado só.** Proibido partir a peça para usinar: fio EDM com o arame entrando pela boca
   de entrada Ø75,60 e polimento na direção da extrusão. Sombra de usinagem medida no
   modelo: 0,00 % de área sem acesso reto.

## Interface com o EX-030 (medida na montagem `3D/Cabecote_EX-030_com_Matriz_Jonatha_v30.step`)

  - Ø94,00 em Z 0,00 → 69,90 · folga radial 0,50 mm no furo Ø95,00
  - Ø89,00 em Z 69,90 → 80,70 · folga radial 0,50 mm no furo Ø90,00
  - Ø79,00 em Z 80,70 → 95,00 · folga radial 0,50 mm no furo Ø80,00

Interferência matriz × cabeçote: **0,0000 mm³** (zero é o certo — a matriz desliza nos
furos e encosta face a face no rebaixo, `deslocamento_aplicado_mm` = 0,00).

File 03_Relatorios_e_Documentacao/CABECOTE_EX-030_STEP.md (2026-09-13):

# Cabeçote EX-030 em STEP — sem a parte que conecta na extrusora

Os dois sólidos vêm do que foi **medido no DWG 030-032** (`cabecote_ex030.json`) e do mesmo
construtor que o verificador de interface usa, com o booleano abaixo:

``
python 04_Dados_SSOT_e_Scripts/gerar_cabecote_ex030.py        # gera, mede e prova
``

| arquivo | o que é |
| :--- | :--- |
| `06_CAD_Cabecote_EX-030/STEP/Cabecote_EX-030_sem_flange.step` | **o pedido**: corpo Ø130 × 95,000 mm com o nariz Ø80, o degrau Ø90 e o bolso Ø95 × 71,000 mm |
| `06_CAD_Cabecote_EX-030/STEP/Cabecote_EX-030_desenhado.step` | o cabeçote como está no desenho (cubo + flange + resalto), para referência e para a subtração |

## O cabeçote com cada matriz sentada (montagens entregues)

Dois arquivos compostos, no mesmo referencial axial (Z = 0 no plano mais traseiro), **sem booleano
nenhum**: cada sólido é o que está no arquivo de origem, no lugar onde a medição o põe.** A montagem da
Copo tem 2 sólidos (ela é de corpo único) e a da Gedeon tem 3 (cabeçote + Body_A + Body_B). Isso foi
corrigido depois da primeira versão, que entregava a matriz unida (A ∪ B): a união é válida e é com
ela que a folga é medida, mas ela conserva as cavidades internas seladas dos sólidos de origem - e
sólido com casca interna é o que abre como "peça quebrada" na maioria dos visualizadores de STEP.
Medido hoje, nos arquivos tais como estão no repositório: `MatrizGedeon_Body_A.step` é **1 sólido com
3 cascas** (duas cavidades fechadas dentro dele), o `Body_B` tem 1, e a união fica com 3. Numa
montagem, a bipartição é o dado, não um detalhe a esconder: as metades vão separadas. As duas se
tocam no plano de partição e não se sobrepõem (A ∪ B = 469.156,8 mm³ contra A + B = 469.156,7 mm³),
então somar a interferência peça a peça dá o mesmo número que o booleano sobre a união.

O `[3, 1]` do `MatrizJonatha.step` (v27, master) é a mesma moléstia, e é o G-03 da auditoria: bolsões de
pino selados num corpo e ausentes no outro. A v28.1 é o remédio proposto - 4 bolsões abertos no plano
de partição e cegos sob o fundo nos DOIS corpos, com parede mínima medida de 2,391 a 2,483 mm até o
canal e 0,000000 mm³ de comunicação com o fluxo.
partição e não se sobrepõem (medido: A ∪ B = 469.156,8 mm³ contra A + B = 469.156,7 mm³), então somar a
interferência peça a peça dá o mesmo número que o booleano sobre a união.

As matrizes são lidas de `02_CAD_Modelos_Historicos/` / `01_CAD_MatrizJonatha_Oficial/` **sem
modificar** (regra 2). A medição da folga usa A ∪ B — o mesmo corpo que
`medir_perfis_matrizes_x_cabecote.py` mede, para o STEP entregue e a medição não divergirem;
a entrega usa as metades separadas, como explicado acima.

| montagem | sólidos no arquivo | encosto usado | interferência com o cabeçote | saída em Z | protrusão |
| :--- | ---: | :--- | ---: | ---: | ---: |
| `Cabecote_EX-030_com_Matriz_Copo.step` | 2 (1 + 1) | `B_ombro_no_degrau` (0,00 mm) | **0,0000 mm³** | 80,70 | -14,30 mm |
| `Cabecote_EX-030_com_Matriz_Gedeon.step` | 3 (1 + 2) | `B_ombro_no_degrau` (0,00 mm) | **0,0000 mm³** | 109,00 | 14,00 mm |
| `Cabecote_EX-030_com_Matriz_Gedeon_Certa.step` | 2 (1 + 1) | `B_ombro_no_degrau` (0,00 mm) | **0,0000 mm³** | 109,00 | 14,00 mm |
| `Cabecote_EX-030_com_Matriz_Desenvolvimento.step` | 3 (1 + 2) | `B_ombro_no_degrau` (0,00 mm) | **0,0000 mm³** | 109,00 | 14,00 mm |
| `Cabecote_EX-030_com_Matriz_Jonatha_v27.step` | 3 (1 + 2) | `B_ombro_no_degrau` (0,00 mm) | **0,0000 mm³** | 109,00 | 14,00 mm |
| `Cabecote_EX-030_com_Matriz_Jonatha_v28_1.step` | 3 (1 + 2) | `B_ombro_no_degrau` (0,00 mm) | **0,0000 mm³** | 109,00 | 14,00 mm |

### O que cada arquivo de matriz realmente contém (medido, não narrado)

Isto existe porque a pergunta 'a Gedeon está corrompida?' só se responde abrindo os arquivos. Nenhum
deles é inválido — o que corrompe a leitura é *quantos* sólidos tem cada um e o que eles são:

| arquivo | sólidos | volume total | sólidos válidos | cascas por sólido |
| :--- | ---: | ---: | :--- | :--- |
| `MatrizGedeon.step (inteira)` | 5 | 683,248.4 mm³ | [True, True, True, True, True] | [1, 1, 1, 1, 1] |
| `MatrizGedeon_Body_A.step` | 1 | 234,332.8 mm³ | [True] | [3] |
| `MatrizGedeon_Body_B.step` | 1 | 234,823.9 mm³ | [True] | [1] |
| `MatrizGedeon_Canal_Fluxo.step` | 1 | 213,790.0 mm³ | [True] | [1] |
| `Matriz1_Original_Copo_Solido.step` | 1 | 224,289.0 mm³ | [True] | [1] |
| `MatrizJonatha.step (master v27)` | 2 | 469,001.7 mm³ | [True, True] | [3, 1] |

`MatrizGedeon.step` (a inteira) são **5 sólidos**: as duas metades **sem o canal escavado**
(320.090,4 mm³ cada), o sólido do canal de plástico (43.017,9 mm³, boca Ø75,60, Z 0..109) e dois pinos
de 24,9 mm³. Aberto num visualizador, isso é corpo + corpo dentro do corpo + vazio virando sólido dentro
dos dois — daí o aspecto de arquivo quebrado. Os STEP que o projeto usa são os outros:
`MatrizGedeon_Body_A.step` e `_Body_B.step`, as metades **com** o canal escavado (234.332,8 + 234.823,9
= 469.156,7 mm³, e a união dá 469.156,8: elas se tocam, não se sobrepõem).

E o achado velho, re-confirmado por medida: `MatrizGedeon_Canal_Fluxo.step` tem **213.790,0 mm³** contra
os **43.017,9 mm³** do sólido de canal que está dentro de `MatrizGedeon.step` — o arquivo do canal da
Gedeon não é o canal da Gedeon (é a P5 da triagem; é por isso que toda comparação desta tacada usa as
metades, nunca esse arquivo).

### A fenda não está no cabeçote — e o 'copo' que se vê é o bolso dele

`Cabecote_EX-030_sem_flange.step` tem **1 sólido, 1 casca, 11 faces, 610.588,2 mm³** (medido
reimportando o arquivo): não há matriz nenhuma ali dentro. A fenda 75,00 × 1,50 vive na matriz, não no
cabeçote. O que se vê por dentro é a escada de furos do próprio cabeçote — Ø80 (nariz, 14,02) → Ø90
(degrau, 11,00) → Ø95 × 70,00 (o bolso onde a banda da matriz entra) — que é exatamente o copo da matriz
em negativo, e é isso que faz a matriz passar pelo nariz sem tocar a fenda.

### Por que a Gedeon montada parece a Jonatha

Porque são gêmeas de envelope: Gedeon (A ∪ B) 469.156,8 mm³, Jonatha v27 469.001,7 mm³ (0,03 % de
diferença) e Jonatha v28.1 456.796,5 mm³, com a caixa externa idêntica (±46,50 × Z 0..109,00). O que as
separa é interno - funil, canal e bolsões de pino - e não aparece na silhueta lateral. É também por isso
que a exigência do projeto é 'envelope externo idêntico': é o que faz as duas entrarem no mesmo cabeçote.

| `06_CAD_Cabecote_EX-030/STEP/Cabecote_EX-030_com_Matriz_Copo.step` | `B_ombro_no_degrau` (0,00 mm) | **0,0000 mm³** | 80,70 | -14,30 mm |
| `06_CAD_Cabecote_EX-030/STEP/Cabecote_EX-030_com_Matriz_Gedeon.step` | `B_ombro_no_degrau` (0,00 mm) | **0,0000 mm³** | 109,00 | 14,00 mm |
| `06_CAD_Cabecote_EX-030/STEP/Cabecote_EX-030_com_Matriz_Gedeon_Certa.step` | `B_ombro_no_degrau` (0,00 mm) | **0,0000 mm³** | 109,00 | 14,00 mm |
| `06_CAD_Cabecote_EX-030/STEP/Cabecote_EX-030_com_Matriz_Desenvolvimento.step` | `B_ombro_no_degrau` (0,00 mm) | **0,0000 mm³** | 109,00 | 14,00 mm |
| `06_CAD_Cabecote_EX-030/STEP/Cabecote_EX-030_com_Matriz_Jonatha_v27.step` | `B_ombro_no_degrau` (0,00 mm) | **0,0000 mm³** | 109,00 | 14,00 mm |
| `06_CAD_Cabecote_EX-030/STEP/Cabecote_EX-030_com_Matriz_Jonatha_v28_1.step` | `B_ombro_no_degrau` (0,00 mm) | **0,0000 mm³** | 109,00 | 14,00 mm |

A diferença de sinal entre as duas linhas é o ponto que o usuário observou na máquina: a Copo termina
**14,30 mm antes** da face do nariz (falta o nariz de 28,30 mm que a Gedeon tem), e a Gedeon desemboca
fora dele. Os dois valores são comprimentos medidos nos STEP das próprias peças: 80,70, 109,00, 109,00, 109,00, 109,00, 109,00 mm.

## O que foi removido, e como isso foi definido

Remover = intersectar pelo cilindro Ø130 do corpo. A definição não é arbitrária: a junta
cabeçote↔extrusora é exatamente o que está fora do corpo, medido em anéis:

* Ø220 (d 52.00..92.00);
* os 6 furos Ø16,500 em C.C. Ø180,000 ficam a 90,000 mm do eixo, **todos** fora de r = 65,000 mm — o corte leva os seis junto com o flange, sem precisar de furo novo e sem tocar em nenhuma face de centragem.

## O que a medição do sólido prova

* volume 1570339 → 610588 mm³; massa **12,327 → 4,793 kg**, foram **7,534 kg** de aço a menos (61,1 % do volume) — a conta do material e do tempo de usinagem muda de verdade;
* **0,0000 mm³** de metal removido até r = 46,50 mm, que é a banda Ø93 em que a matriz é apertada: o bolso Ø95, o degrau Ø90→Ø95 (a face que reage os 29,8 kN de empuxo) e o nariz Ø80 continuam os do desenho, milímetro por milímetro;
* comprimento axial **95,000 mm**, igual ao do desenho (95,000 mm), e a bounding box ficou Ø130,000 × Ø130,000: corpo redondo, sem nada sobrando da junta;
* na parede do bolso (entre a banda Ø93 e o furo Ø95): 0,000 mm³ removidos pelo corte — o Ø12 do M12, se ele for transversal, abre 1,00 mm além da banda da matriz, na parede onde o collete EX-031 encosta, e não na matriz;
* interferência com `MatrizJonatha_v28.step`: **0,0000 mm³** (no cabeçote com flange: 0,0000 mm³) — a matriz entra, senta no degrau e sai da mesma maneira na variante sem flange.

## O que o corte NÃO resolve (lê antes de mandar usinar)

1. **Sem o flange, a peça não se fixa em lugar nenhum.** Os 6 × M12 eram a única interface mecânica com a extrusora, e é o aperto deles que segura o conjunto contra o empuxo do fundido. Este STEP serve para ver montagem, volume, massa e interface com a matriz. Para fabricar, a junta precisa de substituto (flange de outro diâmetro, grampos no corpo, ou apoio direto na boca da extrusora usando os centragens que já existem).
2. **O M12 transversal ficou fora do modelo.** Medido: par de círculos concêntricos Ø10,500/Ø12,000 com marca de centro sobre o eixo a 72,020 mm da face do nariz (= 20,000 mm da face do flange — é daí que sai o '20' cotado, e é por isso que aquele '20' não é a protrusão da matriz). No arquivo que chegou ele não tem aresta de seção correspondente em parte nenhuma, então a natureza exata (furo roscado transversal, abrindo na banda onde o collete aperta, ou furo coaxial no fundo do bolso para o pushador EX-032) não é determinável. Modelar `--com-m12` abre o Ø12 atravessando as duas paredes no ângulo que você especifar (padrão 90°) para você ver o cenário — e nada neste STEP depende dele.
3. Nada aqui mexe na matriz: `MatrizJonatha.step` continua o v27.0 aprovado e a v28.1 continua proposta (decisão D4).

*Gerado por `gerar_cabecote_ex030.py`; medições em `04_Dados_SSOT_e_Scripts/cabecote_step.json`.*

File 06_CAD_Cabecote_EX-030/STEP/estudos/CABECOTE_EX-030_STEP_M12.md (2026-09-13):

# Cabeçote EX-030 em STEP — sem a parte que conecta na extrusora

Os dois sólidos vêm do que foi **medido no DWG 030-032** (`cabecote_ex030.json`) e do mesmo
construtor que o verificador de interface usa, com o booleano abaixo:

``
python 04_Dados_SSOT_e_Scripts/gerar_cabecote_ex030.py        # gera, mede e prova
``

| arquivo | o que é |
| :--- | :--- |
| `06_CAD_Cabecote_EX-030/STEP/estudos/Cabecote_EX-030_sem_flange_M12.step` | **o pedido**: corpo Ø130 × 95,000 mm com o nariz Ø80, o degrau Ø90 e o bolso Ø95 × 71,000 mm |
| `06_CAD_Cabecote_EX-030/STEP/estudos/Cabecote_EX-030_desenhado_M12.step` | o cabeçote como está no desenho (cubo + flange + resalto), para referência e para a subtração |

## O que foi removido, e como isso foi definido

Remover = intersectar pelo cilindro Ø130 do corpo. A definição não é arbitrária: a junta
cabeçote↔extrusora é exatamente o que está fora do corpo, medido em anéis:

* Ø203 (d 91.00..95.00);
* Ø220 (d 51.00..93.00);
* os 6 furos Ø16,500 em C.C. Ø180,000 ficam a 90,000 mm do eixo, **todos** fora de r = 65,000 mm — o corte leva os seis junto com o flange, sem precisar de furo novo e sem tocar em nenhuma face de centragem.

## O que a medição do sólido prova

* volume 1662551 → 620465 mm³; massa **13,051 → 4,871 kg**, foram **8,180 kg** de aço a menos (62,7 % do volume) — a conta do material e do tempo de usinagem muda de verdade;
* **0,0000 mm³** de metal removido até r = 46,50 mm, que é a banda Ø93 em que a matriz é apertada: o bolso Ø95, o degrau Ø90→Ø95 (a face que reage os 29,8 kN de empuxo) e o nariz Ø80 continuam os do desenho, milímetro por milímetro;
* comprimento axial **95,000 mm**, igual ao do desenho (95,000 mm), e a bounding box ficou Ø130,000 × Ø130,000: corpo redondo, sem nada sobrando da junta;
* na parede do bolso (entre a banda Ø93 e o furo Ø95): 0,225 mm³ removidos pelo corte — o Ø12 do M12, se ele for transversal, abre 1,00 mm além da banda da matriz, na parede onde o collete EX-031 encosta, e não na matriz;
* interferência com `MatrizJonatha_v28.step`: **0,0000 mm³** (no cabeçote com flange: 0,0000 mm³) — a matriz entra, senta no degrau e sai da mesma maneira na variante sem flange.

## O que o corte NÃO resolve (lê antes de mandar usinar)

1. **Sem o flange, a peça não se fixa em lugar nenhum.** Os 6 × M12 eram a única interface mecânica com a extrusora, e é o aperto deles que segura o conjunto contra o empuxo do fundido. Este STEP serve para ver montagem, volume, massa e interface com a matriz. Para fabricar, a junta precisa de substituto (flange de outro diâmetro, grampos no corpo, ou apoio direto na boca da extrusora usando os centragens que já existem).
2. **O M12 transversal ficou fora do modelo.** Medido: par de círculos concêntricos Ø10,500/Ø12,000 com marca de centro sobre o eixo a 72,020 mm da face do nariz (= 20,000 mm da face do flange — é daí que sai o '20' cotado, e é por isso que aquele '20' não é a protrusão da matriz). No arquivo que chegou ele não tem aresta de seção correspondente em parte nenhuma, então a natureza exata (furo roscado transversal, abrindo na banda onde o collete aperta, ou furo coaxial no fundo do bolso para o pushador EX-032) não é determinável. Modelar `--com-m12` abre o Ø12 atravessando as duas paredes no ângulo que você especifar (padrão 90°) para você ver o cenário — e nada neste STEP depende dele.
3. Nada aqui mexe na matriz: `MatrizJonatha.step` continua o v27.0 aprovado e a v28.1 continua proposta (decisão D4).

*Gerado por `gerar_cabecote_ex030.py`; medições em `04_Dados_SSOT_e_Scripts/cabecote_step.json`.*

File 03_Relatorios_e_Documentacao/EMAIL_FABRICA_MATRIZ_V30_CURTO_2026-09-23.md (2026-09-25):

# E-mail curto para a fábrica — matriz v30, anexando só os STEP (2026-09-23)

Você vai mandar a pasta `08_Pacote_Usinagem_v30/3D/` (3 arquivos). Sem o desenho, as cotas têm de ir no corpo
do e-mail — é o que está abaixo. Cole o bloco do e-mail inteiro, sem cortar as linhas de `·`: cada uma delas é
uma cota que a fábrica precisa ter por escrito para poder ser cobrada depois.

Antes de enviar, confira os três arquivos (tamanho e sha256). Se algum bater diferente, você está mandando
outra revisão:

| arquivo | bytes | sha256 (SHA-256) |
|---|---:|---|
| `MATRIZ_V30_PECA_UNICA.step` | 97.198 | `b42ee2e50a10d43db4b91a22f62e3e4e0aacfdcd8e3ebbacf3eb6cf4a39b818e` |
| `MATRIZ_V30_CANAL_DE_FLUXO.step` | 85.455 | `77497bf86c989b23d8eb121c5318904c7ca506a3b580c89ecde134f0873f2154` |
| `Cabecote_EX-030_com_Matriz_Jonatha_v30.step` | 151.083 | `725c2f83f26cc6e85331182e8e86d60d5fe9cd172405271228f0b03fbd7128a5` |

Comando: `cd 08_Pacote_Usinagem_v30/3D && sha256sum *`.

---

## O e-mail

**Assunto:** 1 matriz JONATHA v27.0 (rev. 30) · aço 1045 · fenda 1,500 +0,010/−0,000 aberta a fio EDM depois do T.T.

Boa tarde,

Pedido de fabricação de **1 (uma) matriz de extrusão**, peça única, sem lote, para o cabeçote EX-030. Os três
STEP anexos definem a geometria: `MATRIZ_V30_PECA_UNICA.step` é a peça, `MATRIZ_V30_CANAL_DE_FLUXO.step` é o
sólido do canal (para o fio EDM) e `Cabecote_EX-030_com_Matriz_Jonatha_v30.step` mostra como a peça senta no
cabeçote. O que tem de sair:

· **MATERIAL: aço 1045** (SAE J404 / EN 10083-2), barra forjada, fibra no eixo, normalizada ≤ 220 HB; corpo revenido
30-36 HRC; **arestas do land 55-60 HRC em camada 0,6-1,0 mm por indução**, ou nitretação a plasma 600-700 HV0,2
— escolha de vocês, declarada no relatório; sem PVD/DLC.

· **Ø94,00 ±0,5** (datum A, Z 0 → 69,90) · **Ø89,00 ±0,5** (69,90 → 80,70) · **Ø79,00 ±0,5** (80,70 → 95,00) ·
comprimento **95,00 ±0,5** · degraus com ±0,05 · coaxialidade dos três estágios **Ø0,02** · face de saída
planeza 0,01 e perpendicularidade 0,01 em A.
· **land 8,50 ±0,05** (Z 85,00 → 93,50) · fenda **75,00 × 1,500 +0,010/−0,000** com **R 0,75** nas pontas,
aresta viva · área da seção no land **112,0171 mm² ±0,5 %** (fora disso é rejeição) · chanfro 1,50 × 45°
(boca 78,00 × 4,50) · boca de entrada **Ø75,60 +0,05/−0,00, não alargar** · Ra ≤ 0,4 µm no canal e no land,
polido na direção da extrusão · Ra ≤ 0,8 µm nos Ø de envelope · rebarba ≤ 0,1 × 45°.
· **Sequência:** T.T. do corpo → retífica do land → **fio EDM do canal** (arame pela boca de Ø75,60, de um lado
só) → remover camada REC ≥ 0,02 mm → indução/nitretação → medição final. **Meçam a abertura da fenda antes e
depois do tratamento e gravem os dois números**; camada de 8-18 µm por face come 0,016-0,036 mm de uma
tolerância de +0,010/−0,000.
· **Proibido:** furo de fixação, flange, rosca, pino e linha de partição. A peça é 1 sólido e é segurada pelo
collete EX-031 e pelo degrau do furo do cabeçote.
· **Desenho em CAD, como você pediu:** vão junto dois DXF da mesma folha A3 (três vistas, 8 cotas, tabela de
anatomia, MATERIAL em destaque) — `MATRIZ_V30_DESENHO_COTADO_AC1015.dxf` para CAD antigo e
`MATRIZ_V30_DESENHO_COTADO.dxf` (AC1024) para AutoCAD recente — mais o `MATRIZ_V30_DESENHO_COTADO_PREVIEW.pdf`
para ver no celular. Os `.STEP` são texto ASCII `ISO-10303-21`: se abriu como "binário", foi o visualizador.
DWG você tira deles em Abrir → Salvar como, a geometria não muda. **O que vincula continuam sendo os STEP** —
o desenho é convenção de leitura, se divergir de mim avise antes de usinar.

Preciso de: prazo, preço, e a confirmação de se vocês fecham o comprimento em **95,00 −0,50/+0,00** (com +0,5
a face passaria 0,5 mm para fora do nariz). Dossiê na entrega: certificado EN 10204 3.1 do calor + relatório
dimensional com as cotas acima + microdureza em seção. Marcação a laser na face traseira:
`JONATHA v27.0 · EX-031 · 1045 · rev. 30 (2026-09-22) · lote · nº de série · data`. NDA antes de o desenho
circular internamente — o projeto está em patenteamento.

Att,
[nome] · [telefone]

---

## A folha em PDF é opcional — para o celular dele já basta o `PREVIEW.pdf` do DXF

`08_Pacote_Usinagem_v30/FOLHA_DE_COTAS_V30.pdf` — uma página, refeita hoje (23/09) para o tamanho de letra e o
pouco texto que você pediu. Cinco blocos: **faixa de MATERIAL no topo** — o aço 1045 em corpo grande, com a
norma (SAE J404 / EN 10083-2, barra forjada, fibra no eixo, normalizada ≤ 220 HB), a dureza do corpo e do land,
indução × nitretação como escolha de vocês, e o "sem PVD/DLC e sem trocar de aço"; **meia-seção no plano da
abertura** (é onde aparece o funil/cone interno, que na versão anterior não aparecia); **DETALHE A ampliado do
fim do canal** com a abertura 1,500 +0,010/−0,000 escrita grande; **face de saída** com largura e abertura da
fenda; e **regras** em três colunas curtas (ordem de fabricação, proibido, aceitação). Saíram da folha a prancha
densa, os balões numerados e o quadro de notas — nada de número chutado: a folha é gerada do mesmo
`pacote_usinagem.json` medido no STEP (`desenhar_folha_de_cotas_v30.py`), e por isso bate com as cotas deste
e-mail. Não está dentro do `PACOTE_MATRIZ_V30_PARA_ENVIO.zip` (o zip e os hashes publicados não mudaram). Se
você anexar a folha, mande junto o `CHECKSUMS_SHA256.txt`? Não — ela é informativa; o que vincula é o STEP e o
que está escrito acima.

## O DXF cotado da matriz — foi exatamente o que a matrizaria pediu (24/09, 10:01)

`08_Pacote_Usinagem_v30/MATRIZ_V30_DESENHO_COTADO.dxf` — A3, **1:1, milímetros, 8 cotas** e mais nada de
texto solto. A folha é geometria: três vistas (**seção no plano da abertura 1:1** — é aí que o funil aparece;
**face de saída 1:1** com a fenda e a boca do chanfro com os raios de verdade; **DETALHE A 6:1** do fim do
canal, onde a `ABERTURA 1,500 +0,010/-0,000` está escrita grande) e uma **tabela de anatomia de 13 linhas**
com três colunas: região / cota de contrato / o que a medição no STEP achou. As 13 linhas, na ordem: face de
entrada (planicidade do datum), Ø dos 3 estágios, posição dos degraus 1→2 e 2→3, coaxialidade, boca de
entrada, funil em spline, raio da junção funil-fenda, land com a faixa axial, abertura da fenda, largura da
fenda, raio das duas pontas, chanfro com a boca, comprimento total. O **material** é a linha de topo, em corpo grande: `MATERIAL: AÇO 1045 · SEM PVD ·
SEM DLC · SEM OUTRO AÇO`, com a norma e a dureza logo abaixo; e ele volta em vermelho no carimbo. Da
fabricação ficou **uma** linha no rodapé da tabela (fio EDM pelo Ø75,60 de um lado só depois do tratamento,
medir a abertura antes e depois, sem furo/flange/rosca/pino/linha de partição, certificado EN 10204 3.1 e
relatório dimensional) — o passo a passo está no `03_SEQUENCIA_DE_USINAGEM.md` do pacote, não na folha.
As 8 cotas são `DIMENSION` verdadeiras: eles medem, editam e importam no CAD. A geometria é a nominal exata
medida no STEP, então o número lido no arquivo bate com o texto da cota; o `audit()` do ezdxf fechou em zero
erros e nenhuma etiqueta da folha se sobrepõe a outra. Dois avisos: o `Ø` pode não aparecer se a fonte do
texto do CAD não tiver Latin-1 (trocaram para Arial, o arquivo não muda), e o desenho é informativo — o que
vincula continuam sendo os STEPs. Saíram junto, para ver sem abrir CAD: `_PREVIEW.png` e `_PREVIEW.pdf`.
Há dois arquivos da mesma folha, e a escolha é pela idade do CAD deles: `MATRIZ_V30_DESENHO_COTADO_AC1015.dxf`
(AutoCAD 2000, acentos em cp1252 de um byte, sem escape `\U+`) abre em qualquer coisa que exista na oficina;
`MATRIZ_V30_DESENHO_COTADO.dxf` (AC1024) é o padrão para CAD recente. **Se você tiver de mandar um só, mande
o AC1015.** Os dois passam as mesmas travas (0 erros de `audit()`, 8/8 cotas conferidas, 0 etiquetas
sobrepostas) e o conteúdo é byte a byte a mesma folha; quem os gerou foi o mesmo script, `DXF_SERIE=R2000` no
segundo caso. E por escrito o pedido dele: "se não abrir o DXF aí, diga qual versão de AutoCAD vocês usam que
eu te mando a mesma folha nela" — nós não inventamos DWG, mas DXF em qualquer versão do AC1015 para cima é só
rodar o script.
Nada disso está dentro do `PACOTE_MATRIZ_V30_PARA_ENVIO.zip` (o zip e os hashes publicados não mudaram).
A v29 tem o desenho dela na pasta `_v29` (comprimento 109,00, land de 99,00 a 107,50, protrusão 14,00).

**Não mande:** o resto do pacote (a prancha grande, os relatórios, o `pacote_usinagem.json`), os modelos
históricos, a v29, o DXF do cabeçote (só a matriz tem desenho cotado) e qualquer script daqui. Peça só 1 matriz — se eles oferecerem lote,
recuse por escrito.

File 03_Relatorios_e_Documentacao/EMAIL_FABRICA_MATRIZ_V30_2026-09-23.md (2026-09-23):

# E-mail objetivo para a fábrica — matriz v30 (2026-09-23)

Pronto para copiar e colar. Os números abaixo são transcritos do `08_Pacote_Usinagem_v30/`
(medidos no STEP `3D/MATRIZ_V30_PECA_UNICA.step`, sha256 `b42ee2e50a10d43d…`), não de memória.
O sha256 do anexo citado no corpo é o do zip publicado hoje — se o pacote for re-gerado, conferir
o valor em `08_Pacote_Usinagem_v30/07_EMAIL_DE_PRIMEIRO_CONTATO.md` antes de enviar.

---

## O e-mail

**Assunto:** Pedido de fabricação — 1 matriz de extrusão JONATHA v27.0 (rev. 30) · aço 1045 · fenda 1,500 mm a fio EDM pós-T.T.

**Anexo:** `PACOTE_MATRIZ_V30_PARA_ENVIO.zip` (588.274 bytes)

Boa tarde,

Seguimos do orçamento para o pedido. Preciso de **1 (uma) matriz de extrusão**, peça única, sem lote,
para o cabeçote EX-030. Geometria, tolerâncias e sequência estão no pacote anexo; o que segue é o resumo
que precisa estar bater com a proposta.

**A peça.** Ø94,00 × 95,00 mm, 3,442 kg, em **aço 1045** (SAE J404 / EN 10083-2, barra forjada, fibra no
eixo, normalizada ≤ 220 HB).

| cota | valor | tolerância |
|---|---:|---|
| 1º estágio (datum A) | Ø94,00, Z 0 → 69,90 | ±0,5 · micrômetro em 3 posições a 120° |
| 2º estágio | Ø89,00, Z 69,90 → 80,70 | ±0,5 |
| 3º estágio / pescoço | Ø79,00, Z 80,70 → 95,00 | ±0,5 |
| comprimento total | 95,00 | ±0,5 (ver pergunta 1) |
| posição dos dois degraus | 69,90 / 80,70 | ±0,05 · CMM |
| coaxialidade dos estágios 2 e 3 em relação a A | — | Ø0,02 |
| face de saída | — | planeza 0,01 e ⟂ 0,01 em A |
| **land paralelo** | 8,500 (Z 85,00 → 93,50) | ±0,05 |
| **fenda no land** | largura 75,000 × **abertura 1,500** | largura ±0,05 · **abertura +0,010 / −0,000** |
| raio nas pontas da fenda | R 0,75 | +0,05 / −0,00 · aresta viva, sem raio extra |
| área da seção no land | 112,0171 mm² | **±0,5 % — rejeição fora disso** |
| chanfro de saída | 1,50 × 45° (Z 93,50 → 95,00), boca 78,00 × 4,50 | ±0,20 / ângulo ±0,5° |
| boca de entrada do canal | Ø75,60 | +0,05 / −0,00 — **não alargar** |
| raio no fundo do funil | R 3,0 ±0,5 | sem aresta viva |
| rugosidade | Ra ≤ 0,4 µm no canal e land (polir **na direção da extrusão**); ≤ 0,8 µm nos Ø de envelope | |
| rebarba / quebra de aresta | máx. 0,1 × 45°, inclusive na boca de saída | |

**As quatro condições que não são negociáveis.**

1. **Sem furo de fixação, sem flange, sem rosca, sem pino.** A matriz é segurada pelo collete EX-031 e pelo
   degrau do furo do cabeçote. Qualquer furo "para ajudar a segurar" é rejeição — ele entra na zona de aperto
   do degrau. Elemento de aperto só em estoque, fora do envelope final e antes do tratamento térmico.
2. **Peça única, 1 sólido, sem linha de partição.** Não usinar em duas metades e colar: a costura no plano
   Y = 0 é exatamente o defeito que estamos eliminando.
3. **Canal aberto por fio EDM de um lado só**, com o arame entrando pela boca de Ø75,60; sombra de usinagem
   medida no modelo: 0,00 % (não há face sem acesso reto).
4. **Sequência: T.T. do corpo → retífica do land → fio EDM do canal → remoção da camada REC (≥ 0,02 mm) →
   indução/nitretação → medição final.** A fenda não pode existir antes do tratamento térmico do corpo
   (risco de trinca: 1,500 mm atravessando 95 mm de 1045 temperado), e a camada REC do EDM tem de sair toda.

**Tratamento superficial na fenda (pedido nosso).** Corpo revenido **30-36 HRC**; arestas do land
**55-60 HRC em camada de 0,6-1,0 mm por indução**, **ou** nitretação a plasma 520 °C (600-700 HV0,2, camada
branca 8-18 µm) se vocês preferirem tratar a fenda inteira — escolha da fábrica, declarada no relatório.
Atenção à cota: 8-18 µm por face come 0,016-0,036 mm de uma abertura que tolera +0,010/−0,000, e a indução
move 0,005-0,020 mm na zona tratada. Portanto **medir a abertura da fenda antes e depois do tratamento e
gravar os dois números** no relatório dimensional; se a abertura cair de 1,500, o retrabalho é passar o fio
de novo na região e re-medir — não é "aceitar como está". Sem revestimento PVD/DLC: não foi pedido.

**Documentos que acompanham a peça.** Certificado EN 10204 3.1 do calor (composição, granulometria,
inclusões, resultado de têmpera/revenimento); relatório dimensional com os números medidos de todas as linhas
da tabela, inclusive as três leituras da fenda (entrada, meio, saída) antes e depois do tratamento; registro
de microdureza em seção (corpo de prova do mesmo lote); marcação a laser na **face traseira**, fora do furo e
fora da face de assentamento: `JONATHA v27.0 · EX-031 · 1045 · rev. 30 (2026-09-22) · lote · nº de série · data`.

**Três respostas antes de eu emitir a ordem de compra.**

1. **Comprimento.** A cota está liberada como 95,00 ±0,5, mas com +0,5 a face de saída passaria 0,5 mm para
   fora do nariz do cabeçote. Nossa intenção é fechar em **95,00 −0,50 / +0,00**. Vocês concordam com o
   aperto ou precisam de mais folga para o comprimento faceado à máquina?
2. **Tratamento.** Indução nas arestas ou nitretação a plasma na fenda inteira — qual caminho vocês dominam
   melhor com controle de camada em peça de 3,4 kg com fenda passante, e é interno ou terceirizado?
3. **Prazo e preço** para 1 matriz com o dossiê completo (usinar + T.T. + fio EDM + tratamento + medição).
   Nossa referência é 20 dias úteis. Se o tratamento terceirizado mandar no prazo, digam o número real.

O pacote anexo tem: STEP AP214 da peça (o modelo é a definição; o desenho cotado é a régua de aceitação),
STEP do sólido do canal para o fio EDM, montagem no cabeçote EX-030, prancha 2D toleranciada em PDF, ficha
de fábrica, material e tratamento, sequência de usinagem, plano de inspeção, RFQ e `CHECKSUMS_SHA256.txt`
com os 13 arquivos. Conferência do anexo: `sha256sum` deve dar
**`0738c4683c80efdb6f3db4903c1d7febe8126ac147d9025c8cfdfbc2dd6fac6e`** em 588.274 bytes. Se o hash não
bater, não abram — peçam reenvio.

É uma peça só, sem lote; o projeto está em patenteamento, então precisamos de NDA assinado antes da difusão
interna do desenho.

Att,
[nome] · [telefone] · [empresa]

---

## O que mandar — e o que não mandar

**Mande exatamente isto (duas peças, nada mais):**

1. O zip `08_Pacote_Usinagem_v30/PACOTE_MATRIZ_V30_PARA_ENVIO.zip` (**588.274 B**, sha256
   `0738c4683c80efdb6f3db4903c1d7febe8126ac147d9025c8cfdfbc2dd6fac6e`) — é o anexo canônico, dentro dele já
   estão os 13 arquivos + `CHECKSUMS_SHA256.txt`.
2. Se o servidor de e-mail deles estrangular anexo ou se a primeira conversa for por WhatsApp/telefone,
   mande **só** a prancha para o orçamento sair: `08_Pacote_Usinagem_v30/PRANCHA_2D_TOLERANCIADA.pdf`
   (**49.582 B**, sha256 `4b0e6ef12bc2058293186dd6032593389c0c29b710158a1769695df83a458b60`). O zip vai depois,
   com a ordem de compra.

**Antes de apertar em enviar**, nesta ordem: (a) `sha256sum` no arquivo que você anexou e comparar com o
número acima; (b) confirmar que você está mandando o pacote **v30**, não o v29 (o v29 é a variante de
109,00 mm que ficou no disco para comparação — ela **não** vai para a fábrica); (c) NDA enviado antes do
desenho, se eles ainda não assinaram.

**Não mande:** o modelo paramétrico/scripts de `04_Dados_SSOT_e_Scripts/`, as planilhas e bandas de
simulação, os relatórios internos de auditoria (`03_`), o STEP do cabeçote EX-030 completo com o furação do
flange (a interface que a peça precisa respeitar já está descrita na prancha e na ficha), o STEP da Gedeon ou
de qualquer matriz histórica, e o DXF original do cabeçote. Nada disso é preciso para orçar ou usinar esta
peça, e o que não circula não precisa de NDA.

**Duas coisas que continuam suas, não da fábrica:** a resposta à pergunta 1 (deixar 95,00 ±0,5 ou fechar em
−0,50/+0,00) e à pergunta 2 (indução × nitretação) — a fábrica pode opinar, mas a decisão vai para o SSOT
aqui dentro antes de a gente responder "pode usinar". E se eles pedirem alteração de qualquer cota do produto
(fenda, land, chanfro, boca de entrada), a resposta é "me enviem por escrito o motivo" — é isso que o portão
do repo compara, linha por linha, contra o STEP.

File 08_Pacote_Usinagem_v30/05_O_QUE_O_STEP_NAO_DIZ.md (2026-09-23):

# O que o STEP não diz (e precisa estar na ordem de serviço)

* **Datum.** O datum A é o cilindro do 1º estágio (Ø94,00, Z 0,00 → 69,90), não a face de entrada; a face de
  entrada é a de encosto e é ela que abre junta com o cabeçote — planeza 0,01 e ⊥ 0,01 em A.
* **Sentido do polimento.** No land, polir na direção da extrusão (Z crescente). Polimento transversal marca a
  manta.
* **Camada REC do EDM.** Remover ≥ 0,02 mm depois do fio; em 1045 revenido, REC sem remoção é onde nasce trinca.
* **Tratamento na fenda** foi pedido de propósito: é o que segura o desgaste das arestas do land num aço que não
  é de trabalho a quente. Mas ele **não** pode mover a abertura de 1,500 — ver `02_`, item 1 a 4.
* **Sem furo de partida** na boca de entrada: o arame entra pelo Ø75,60 já aberto; se a fábrica
  precisar de furo de entrada para o fio, fazê-lo **no excedente** da boca de saída e fechar com o chanfro de
  1,50 × 45° — nunca dentro do canal.
* **Marcação**: só na face traseira, fora do envelope de assentamento, e o carimbo para a fábrica é
  **JONATHA v27.0**; "rev. 29/30" é revisão interna do projeto.
* **Embalagem**: a boca de saída é a superfície funcional mais frágil (arestas do land endurecidas, 1,500 mm de
  vão). Proteger com capa de PE e não empilhar; transporte com a face de entrada apoiada em prato, nunca a de
  saída.
* **O que mudou em relação à revisão que estava no disco**: Ø93,00 → Ø94,00, Ø89,50 → Ø89,00,
  Ø79,50 → Ø79,00, comprimento 109,00 → 95,00 (funil encurtado; land e chanfro movidos rigidamente),
  material 1.2344 50-52 HRC → 1045 com tratamento nas arestas. O canal de fluxo continua o mesmo do master
  aprovado (só o trecho do funil foi comprimido axialmente, X e Y intactos).

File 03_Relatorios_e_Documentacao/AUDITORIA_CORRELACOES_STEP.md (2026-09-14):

# Auditoria dos STEP — o que cada arquivo é e o que eles têm de bater entre si

Gerada por `04_Dados_SSOT_e_Scripts/auditar_step_correlacoes.py` (código de saída 1 se algo diverge, para entrar no portão). Cada número abaixo foi **medido no arquivo** na hora em que este relatório foi escrito, com `cadquery`, face por face: 70 arquivos STEP abertos. Status: **DIVERGENTE**.

## C1 — cota medida × SSOT (as seis peças inteiras)

| matriz | fenda L × e (mm) | R da borda | boca de entrada | estágios Ø × Z (mm) | comprimento | vazio (mm³) | borda da saída | aço (mm³) | massa (kg) | faces | divergência |
|---|---|---|---|---|---|---|---|---|
| `matriz_1_copo_historica` | 75.000 × 1.500 | 0.75 | Ø 75.60 | Ø93.00 Z 0.00..69.90 · Ø89.50 Z 69.90..80.70 · Ø75.60 Z 0.00..70.70 | 80.70 | 318480,7 | meia-lua (R = espessura/2) | 224289,0 | 1.7607 | 24 | {"envelope": "informativo: [[[75.6, 0.0, 70.7], [79.5, 80.7, 109.0]]]", "comprimento": "informativo: [80.7, 109.0]", "nota": "histórica: medida, mas não cobrada pelo contrato (só a fenda)"} |
| `desenvolvimento_historica` | 75.000 × 1.500 | 0.75 | Ø 75.00 | Ø93.00 Z 0.00..69.90 · Ø89.50 Z 69.90..80.70 · Ø79.50 Z 80.70..109.00 | 109.00 | 155370,4 | canto vivo (retangular) | 527576,4 | 4.1415 | 36 | bate |
| `gedeon_certa_arquivo_do_usuario` | 75.000 × 1.500 | 0.75 | Ø 75.60 | Ø93.00 Z 0.00..69.90 · Ø89.50 Z 69.90..80.70 · Ø79.50 Z 80.70..109.00 | 109.00 | 43017,9 | meia-lua (R = espessura/2) | 640180,7 | 5.0254 | 18 | bate |
| `gedeon_entregue_historica` | 75.000 × 1.500 | 0.75 | — | Ø93.00 Z 0.00..69.90 · Ø89.50 Z 69.90..80.70 · Ø79.50 Z 80.70..109.00 | 109.00 | 24,9 | — | 683248,4 | 5.3635 | 51 | bate |
| `jonatha_v27_oficial` | 75.000 × 1.500 | 0.75 | Ø 75.60 | Ø93.00 Z 0.00..69.90 · Ø89.50 Z 69.90..80.70 · Ø79.50 Z 80.70..109.00 | 109.00 | 213945,1 | meia-lua (R = espessura/2) | 469001,7 | 3.6817 | 43 | bate |
| `jonatha_v27_peca_unica` | 75.000 × 1.500 | 0.75 | Ø 75.60 | Ø93.00 Z 0.00..69.90 · Ø89.50 Z 69.90..80.70 · Ø79.50 Z 80.70..109.00 | 109.00 | 213945,1 | meia-lua (R = espessura/2) | 469303,2 | 3.6840 | 22 | bate |
| `jonatha_v28_1_proposta` | 75.000 × 1.500 | 0.75 | Ø 75.60 | Ø93.00 Z 0.00..69.90 · Ø89.50 Z 69.90..80.70 · Ø79.50 Z 80.70..109.00 | 109.00 | 213945,1 | meia-lua (R = espessura/2) | 456796,5 | 3.5859 | 82 | bate |

Tolerâncias cobradas: largura ±0.05, espessura ±0.02, raio ±0.02, boca +0.10/−0.10, envelope ±0.05 mm (ou seja: a metade do que o desenho autoriza). `sem fenda fechada` é legítimo nas peças históricas, que são cinco sólidos que se atravessam e não têm a fenda como face única.

## C2 — metade × metade × peça inteira, e C3 — o `_Canal_Fluxo.step` é o vazio real?

| matriz | A (mm³) | B (mm³) | A+B − (A∪B) | A ∩ B | cascas A/B | cavidade selada | canal do arquivo (mm³) | vazio medido (mm³) | Δ% | leitura |
|---|---|---|---|---|---|---|---|---|---|
| `matriz_1_copo_historica` | 112144,5 | 112144,5 | -0,0000 | 0,0000 | 1/1 | não | 318480,7 | 318480,7 | 0,000 | o arquivo do canal e o vazio da peca |
| `desenvolvimento_historica` | 263637,4 | 263939,0 | 0,0000 | 0,0000 | 1/1 | não | 155370,4 | 155370,4 | 0,000 | o arquivo do canal e o vazio da peca |
| `gedeon_certa_arquivo_do_usuario` | 320090,4 | 320090,4 | -0,0000 | 0,0000 | 1/1 | não | 43017,9 | 43017,9 | 0,000 | o arquivo do canal e o vazio da peca |
| `gedeon_entregue_historica` | 234332,8 | 234823,9 | 0,0000 | 0,0000 | 3/1 | SIM | 213790,0 | 24,9 | 858494,378 | o arquivo do canal NAO e o vazio desta peca |
| `jonatha_v27_oficial` | 234255,3 | 234746,4 | 0,0000 | 0,0000 | 3/1 | SIM | 214246,7 | 213945,1 | 0,141 | o arquivo do canal e o vazio da peca |
| `jonatha_v27_peca_unica` | 0,0 | 0,0 | 0,0000 | 0,0000 | —/— | não | — | — | — | — |
| `jonatha_v28_1_proposta` | 228299,5 | 228497,1 | -0,0316 | 0,0000 | 1/1 | não | 213945,1 | 213945,1 | 0,000 | o arquivo do canal e o vazio da peca |

Casca > 1 num `Body` = cavidade selada dentro do aço, sem ferramenta que a faça: é o G-03 da auditoria de 2026-09-11, presente no `Body_A` da Gedeon entregue e no `MatrizJonatha.step`. E a coluna do canal é a correlação que derrubou a "Gedeon corrigida": o `_Canal_Fluxo.step` histórico carrega o funil da Jonatha, não o vazio da Gedeon.

## C4 — matriz × cabeçote: folga radial, anel de fuga, encosto

Cabeçote medido: `06_CAD_Cabecote_EX-030/STEP/Cabecote_EX-030_desenhado.step` (1570339,5 mm³, 12.327 kg), furo em escada Ø105.00 Z 0.00..3.00 · Ø95.00 Z 0.00..70.00 · Ø90.00 Z 70.00..81.00 · Ø80.00 Z 81.00..95.00, face do nariz em Z = 95.00.

| matriz | folga radial por estágio (mm) | menor folga | anel de fuga contínuo? | área do anel (mm²) | comprimento do anel (mm) | saída além do nariz (mm) | ∩ com o cabeçote (mm³) |
|---|---|---|---|---|---|---|---|
| `matriz_1_copo_historica` | +1.00 / +0.25 / +7.20 | 0.25 | **SIM — caminho livre para trás** | 2238.7 | 151.40 | -14.30 | 0,0000 |
| `desenvolvimento_historica` | +1.00 / +0.25 / +0.25 | 0.25 | **SIM — caminho livre para trás** | 428.4 | 109.00 | +14.00 | 0,0000 |
| `gedeon_certa_arquivo_do_usuario` | +1.00 / +0.25 / +0.25 | 0.25 | **SIM — caminho livre para trás** | 428.4 | 109.00 | +14.00 | 0,0000 |
| `gedeon_entregue_historica` | +1.00 / +0.25 / +0.25 | 0.25 | **SIM — caminho livre para trás** | 428.4 | 109.00 | +14.00 | 0,0000 |
| `jonatha_v27_oficial` | +1.00 / +0.25 / +0.25 | 0.25 | **SIM — caminho livre para trás** | 428.4 | 109.00 | +14.00 | 0,0000 |
| `jonatha_v27_peca_unica` | +1.00 / +0.25 / +0.25 | 0.25 | **SIM — caminho livre para trás** | 428.4 | 109.00 | +14.00 | 0,0000 |
| `jonatha_v28_1_proposta` | +1.00 / +0.25 / +0.25 | 0.25 | **SIM — caminho livre para trás** | 428.4 | 109.00 | +14.00 | 0,0000 |

`anel de fuga contínuo` = existe anel com folga > 0 entre a OD da matriz e o furo do cabeçote, sem pinça, do bico até a face de entrada da matriz. Onde isso é verdadeiro, o mastique **não é obrigado** a passar pela fenda: a rota de trás (para o funil de alimentação) existe e é mais curta que a fenda. É a correlação geométrica que abre a pergunta da simulação.

## C5 — montagem × peças de origem

| montagem | sólidos | volume somado (mm³) | massa (kg) | metal da matriz (mm³) | caixa Ø × Z | válido |
|---|---|---|---|---|---|---|---|
| `Cabecote_EX-030_com_Matriz_Copo.step` | 2 | 1794628,5 | 14.088 | 224289,0 | Ø220.0 × 95.0 | sim |
| `Cabecote_EX-030_com_Matriz_Desenvolvimento.step` | 3 | 2097915,9 | 16.469 | 527576,4 | Ø220.0 × 109.0 | sim |
| `Cabecote_EX-030_com_Matriz_Gedeon.step` | 3 | 2039496,3 | 16.010 | 469156,8 | Ø220.0 × 109.0 | sim |
| `Cabecote_EX-030_com_Matriz_Gedeon_Certa.step` | 2 | 2210520,2 | 17.353 | 640180,7 | Ø220.0 × 109.0 | sim |
| `Cabecote_EX-030_com_Matriz_Jonatha_v27.step` | 3 | 2039341,1 | 16.009 | 469001,7 | Ø220.0 × 109.0 | sim |
| `Cabecote_EX-030_com_Matriz_Jonatha_v27_Peca_Unica.step` | 2 | 2039642,7 | 16.011 | 469303,2 | Ø220.0 × 109.0 | sim |
| `Cabecote_EX-030_com_Matriz_Jonatha_v28_1.step` | 3 | 2027136,0 | 15.913 | 456796,5 | Ø220.0 × 109.0 | **NÃO** |

Toda montagem é o cabeçote **completo com flange** (`Cabecote_EX-030_desenhado.step`) com a matriz sentada no degrau, entregue sem booleano: `1 cabeçote + N` sólidos, onde N é o que o arquivo da matriz tem mesmo (a Gedeon CERTA é 1 sólido; o par bipartido e a v27 são 2; a Gedeon histórica é 2 metades).

## C7 — saúde topológica: BRepCheck em cada sólido, cara e aresta

| arquivo | sólidos | faces | faces inválidas | arestas inválidas | cascas | volume (mm³) |
|---|---|---|---|---|---|---|---|
| `matriz_1_copo_historica` | 2 | 12 | 0 | 0 | 1 | 112144,5 |
| `matriz_1_copo_historica` | 2 | 12 | 0 | 0 | 1 | 112144,5 |
| `matriz_1_copo_historica_Body_A` | 1 | 12 | 0 | 0 | 1 | 112144,5 |
| `matriz_1_copo_historica_Body_B` | 1 | 12 | 0 | 0 | 1 | 112144,5 |
| `matriz_1_copo_historica_Canal_Fluxo` | 1 | 8 | 0 | 0 | 1 | 318480,7 |
| `desenvolvimento_historica` | 2 | 20 | 0 | 0 | 1 | 263637,4 |
| `desenvolvimento_historica` | 2 | 16 | 0 | 0 | 1 | 263939,0 |
| `desenvolvimento_historica_Body_A` | 1 | 20 | 0 | 0 | 1 | 263637,4 |
| `desenvolvimento_historica_Body_B` | 1 | 16 | 0 | 0 | 1 | 263939,0 |
| `desenvolvimento_historica_Canal_Fluxo` | 1 | 12 | 0 | 0 | 1 | 155370,4 |
| `gedeon_certa_arquivo_do_usuario` | 1 | 18 | 0 | 0 | 3 | 640180,7 |
| `gedeon_entregue_historica` | 5 | 19 | 0 | 0 | 1 | 320090,4 |
| `gedeon_entregue_historica` | 5 | 19 | 0 | 0 | 1 | 320090,4 |
| `gedeon_entregue_historica` | 5 | 3 | 0 | 0 | 1 | 24,9 |
| `gedeon_entregue_historica` | 5 | 3 | 0 | 0 | 1 | 24,9 |
| `gedeon_entregue_historica` | 5 | 7 | 0 | 0 | 1 | 43017,9 |
| `gedeon_entregue_historica_Body_A` | 1 | 25 | 0 | 0 | 3 | 234332,8 |
| `gedeon_entregue_historica_Body_B` | 1 | 18 | 0 | 0 | 1 | 234823,9 |
| `gedeon_entregue_historica_Canal_Fluxo` | 1 | 14 | 0 | 0 | 1 | 213790,0 |
| `jonatha_v27_oficial` | 2 | 25 | 0 | 0 | 3 | 234255,3 |
| `jonatha_v27_oficial` | 2 | 18 | 0 | 0 | 1 | 234746,4 |
| `jonatha_v27_oficial_Body_A` | 1 | 25 | 0 | 0 | 3 | 234255,3 |
| `jonatha_v27_oficial_Body_B` | 1 | 18 | 0 | 0 | 1 | 234746,4 |
| `jonatha_v27_oficial_Canal_Fluxo` | 3 | 17 | 0 | 0 | 1 | 213945,1 |
| `jonatha_v27_oficial_Canal_Fluxo` | 3 | 3 | 0 | 0 | 1 | 150,8 |
| `jonatha_v27_oficial_Canal_Fluxo` | 3 | 3 | 0 | 0 | 1 | 150,8 |
| `jonatha_v27_peca_unica` | 1 | 22 | 0 | 0 | 1 | 469303,2 |
| `jonatha_v28_1_proposta` | 2 | 39 | 0 | 0 | 1 | 228299,5 |
| `jonatha_v28_1_proposta` | 2 | 43 | 1 | 0 | 1 | 228497,1 |
| `jonatha_v28_1_proposta_Body_A` | 1 | 39 | 0 | 0 | 1 | 228299,5 |
| `jonatha_v28_1_proposta_Body_B` | 1 | 43 | 1 | 0 | 1 | 228497,1 |
| `jonatha_v28_1_proposta_Canal_Fluxo` | 1 | 20 | 1 | 0 | 1 | 213945,1 |

Achados: jonatha_v28_1_proposta: 1 cara(s) e 0 aresta(s) inválidas em 07_CAD_Matrizes/Matriz_Jonatha_v28_1_PROPOSTA/MatrizJonatha_v28.step (centro [37.02, 0.56, 99.0]); jonatha_v28_1_proposta_Body_B: 1 cara(s) e 0 aresta(s) inválidas em 07_CAD_Matrizes/Matriz_Jonatha_v28_1_PROPOSTA/MatrizJonatha_v28_Body_B.step (centro [37.02, 0.56, 99.0]); jonatha_v28_1_proposta_Canal_Fluxo: 1 cara(s) e 0 aresta(s) inválidas em 07_CAD_Matrizes/Matriz_Jonatha_v28_1_PROPOSTA/MatrizJonatha_v28_Canal_Fluxo.step (centro [37.02, 0.56, 99.0])

## C6 — atalhos e baseline selado

22 caminhos de MODELO selados pelo auditor conferidos byte a byte; divergências: **nenhuma**. Fora do escopo desta checagem (script e JSON do baseline, que esta sessão re-escreveu de propósito; re-selá-los é ato da auditoria): `04_Dados_SSOT_e_Scripts/cad_die_parameters.json`, `04_Dados_SSOT_e_Scripts/cfd_edge_relief.py`, `04_Dados_SSOT_e_Scripts/cfd_land_crosssection.py`, `04_Dados_SSOT_e_Scripts/setup_cfd_env.sh`, `04_Dados_SSOT_e_Scripts/setup_headless_gl.sh`, `04_Dados_SSOT_e_Scripts/verify_geometry_ssot.py`, `04_Dados_SSOT_e_Scripts/verify_legacy_dies.py`, `05_Interface_Auditoria/PROTOCOLO_AUDITORIA.md`, `05_Interface_Auditoria/esquema/proposta.schema.json`, `05_Interface_Auditoria/esquema/veredito.schema.json`, `05_Interface_Auditoria/scripts/auditar_proposta.py`, `05_Interface_Auditoria/scripts/monitor_auditoria.py`, `05_Interface_Auditoria/scripts/painel_auditoria.py`.

## Inventário completo (um bloco por arquivo)

| arquivo | sólidos | cascas | faces | volume (mm³) | caixa Z | fenda | boca | estágios |
|---|---|---|---|---|---|---|---|
| `01_CAD_MatrizJonatha_Oficial/MatrizJonatha.step` | 2 | 3/1 | 43 | 469001,7 | -0.00..109.00 | — | — | — |
| `01_CAD_MatrizJonatha_Oficial/MatrizJonatha_Body_A.step` | 1 | 3 | 25 | 234255,3 | -0.00..109.00 | — | — | — |
| `01_CAD_MatrizJonatha_Oficial/MatrizJonatha_Body_B.step` | 1 | 1 | 18 | 234746,4 | -0.00..109.00 | — | — | — |
| `01_CAD_MatrizJonatha_Oficial/MatrizJonatha_Canal_Fluxo.step` | 3 | 1/1/1 | 23 | 214246,7 | -0.00..109.00 | — | — | — |
| `01_CAD_MatrizJonatha_Oficial/MatrizJonatha_Com_Fluxo.step` | 5 | 3/1/1/1/1 | 66 | 683248,4 | -0.00..109.00 | — | — | — |
| `01_CAD_MatrizJonatha_Oficial/MatrizJonatha_Explodida.step` | 2 | 3/1 | 43 | 469001,7 | -0.00..109.00 | — | — | — |
| `02_CAD_Modelos_Historicos/Matriz1_Original_Copo.step` | 2 | 1/1 | 24 | 224289,0 | 0.00..80.70 | — | — | — |
| `02_CAD_Modelos_Historicos/Matriz1_Original_Copo_Body_A.step` | 1 | 1 | 12 | 112144,5 | 0.00..80.70 | — | — | — |
| `02_CAD_Modelos_Historicos/Matriz1_Original_Copo_Body_B.step` | 1 | 1 | 12 | 112144,5 | 0.00..80.70 | — | — | — |
| `02_CAD_Modelos_Historicos/Matriz1_Original_Copo_Canal_Fluxo.step` | 1 | 1 | 8 | 318480,7 | 0.00..80.70 | — | — | — |
| `02_CAD_Modelos_Historicos/Matriz1_Original_Copo_Explodida.step` | 2 | 1/1 | 24 | 224289,0 | 0.00..80.70 | — | — | — |
| `02_CAD_Modelos_Historicos/Matriz1_Original_Copo_Solido.step` | 1 | 1 | 11 | 224289,0 | 0.00..80.70 | — | — | — |
| `02_CAD_Modelos_Historicos/MatrizDesenvolvimento.step` | 2 | 1/1 | 36 | 527576,4 | -0.00..109.00 | — | — | — |
| `02_CAD_Modelos_Historicos/MatrizDesenvolvimento_Body_A.step` | 1 | 1 | 20 | 263637,4 | -0.00..109.00 | — | — | — |
| `02_CAD_Modelos_Historicos/MatrizDesenvolvimento_Body_B.step` | 1 | 1 | 16 | 263939,0 | -0.00..109.00 | — | — | — |
| `02_CAD_Modelos_Historicos/MatrizDesenvolvimento_Canal_Fluxo.step` | 1 | 1 | 12 | 155370,4 | -0.00..109.00 | — | — | — |
| `02_CAD_Modelos_Historicos/MatrizDesenvolvimento_Com_Fluxo.step` | 3 | 1/1/1 | 48 | 682946,8 | -0.00..109.00 | — | — | — |
| `02_CAD_Modelos_Historicos/MatrizDesenvolvimento_Explodida.step` | 2 | 1/1 | 36 | 527576,4 | -0.00..109.00 | — | — | — |
| `02_CAD_Modelos_Historicos/MatrizGedeon.step` | 5 | 1/1/1/1/1 | 51 | 683248,4 | -0.00..109.00 | — | — | — |
| `02_CAD_Modelos_Historicos/MatrizGedeon_Body_A.step` | 1 | 3 | 25 | 234332,8 | -0.00..109.00 | — | — | — |
| `02_CAD_Modelos_Historicos/MatrizGedeon_Body_B.step` | 1 | 1 | 18 | 234823,9 | -0.00..109.00 | — | — | — |
| `02_CAD_Modelos_Historicos/MatrizGedeon_Canal_Fluxo.step` | 1 | 1 | 14 | 213790,0 | -0.00..109.00 | — | — | — |
| `02_CAD_Modelos_Historicos/matrizGedeonCerta.step` | 1 | 3 | 18 | 640180,7 | -0.00..109.00 | — | — | — |
| `06_CAD_Cabecote_EX-030/STEP/Cabecote_EX-030_com_Matriz_Copo.step` | 2 | 1/1 | 30 | 1794628,5 | 0.00..95.00 | — | — | — |
| `06_CAD_Cabecote_EX-030/STEP/Cabecote_EX-030_com_Matriz_Desenvolvimento.step` | 3 | 1/1/1 | 55 | 2097915,9 | -0.00..109.00 | — | — | — |
| `06_CAD_Cabecote_EX-030/STEP/Cabecote_EX-030_com_Matriz_Gedeon.step` | 3 | 1/3/1 | 62 | 2039496,3 | -0.00..109.00 | — | — | — |
| `06_CAD_Cabecote_EX-030/STEP/Cabecote_EX-030_com_Matriz_Gedeon_Certa.step` | 2 | 1/3 | 37 | 2210520,2 | -0.00..109.00 | — | — | — |
| `06_CAD_Cabecote_EX-030/STEP/Cabecote_EX-030_com_Matriz_Jonatha_v27.step` | 3 | 1/3/1 | 62 | 2039341,1 | -0.00..109.00 | — | — | — |
| `06_CAD_Cabecote_EX-030/STEP/Cabecote_EX-030_com_Matriz_Jonatha_v27_Peca_Unica.step` | 2 | 1/1 | 41 | 2039642,7 | -0.00..109.00 | — | — | — |
| `06_CAD_Cabecote_EX-030/STEP/Cabecote_EX-030_com_Matriz_Jonatha_v28_1.step` | 3 | 1/1/1 | 101 | 2027136,0 | -0.00..109.00 | — | — | — |
| `06_CAD_Cabecote_EX-030/STEP/Cabecote_EX-030_desenhado.step` | 1 | 1 | 19 | 1570339,5 | 0.00..95.00 | — | — | — |
| `06_CAD_Cabecote_EX-030/STEP/Cabecote_EX-030_sem_flange.step` | 1 | 1 | 11 | 610588,2 | 0.00..95.00 | — | — | — |
| `06_CAD_Cabecote_EX-030/STEP/estudos/Cabecote_EX-030_desenhado_M12.step` | 1 | 1 | 19 | 1662551,3 | 0.00..95.00 | — | — | — |
| `06_CAD_Cabecote_EX-030/STEP/estudos/Cabecote_EX-030_sem_flange_M12.step` | 1 | 1 | 11 | 620465,2 | -0.00..95.00 | — | — | — |
| `07_CAD_Matrizes/Matriz_Copo_HISTORICA/Matriz1_Original_Copo.step` | 2 | 1/1 | 24 | 224289,0 | 0.00..80.70 | 75.000×1.500 | Ø75.60 | Ø93.00 · Ø89.50 · Ø75.60 |
| `07_CAD_Matrizes/Matriz_Copo_HISTORICA/Matriz1_Original_Copo_Body_A.step` | 1 | 1 | 12 | 112144,5 | 0.00..80.70 | — | — | — |
| `07_CAD_Matrizes/Matriz_Copo_HISTORICA/Matriz1_Original_Copo_Body_B.step` | 1 | 1 | 12 | 112144,5 | 0.00..80.70 | — | — | — |
| `07_CAD_Matrizes/Matriz_Copo_HISTORICA/Matriz1_Original_Copo_Canal_Fluxo.step` | 1 | 1 | 8 | 318480,7 | 0.00..80.70 | — | — | — |
| `07_CAD_Matrizes/Matriz_Copo_HISTORICA/Matriz1_Original_Copo_Explodida.step` | 2 | 1/1 | 24 | 224289,0 | 0.00..80.70 | — | — | — |
| `07_CAD_Matrizes/Matriz_Copo_HISTORICA/Matriz1_Original_Copo_Solido.step` | 1 | 1 | 11 | 224289,0 | 0.00..80.70 | — | — | — |
| `07_CAD_Matrizes/Matriz_Desenvolvimento_HISTORICA/MatrizDesenvolvimento.step` | 2 | 1/1 | 36 | 527576,4 | -0.00..109.00 | 75.000×1.500 | Ø75.00 | Ø93.00 · Ø89.50 · Ø79.50 |
| `07_CAD_Matrizes/Matriz_Desenvolvimento_HISTORICA/MatrizDesenvolvimento_Body_A.step` | 1 | 1 | 20 | 263637,4 | -0.00..109.00 | — | — | — |
| `07_CAD_Matrizes/Matriz_Desenvolvimento_HISTORICA/MatrizDesenvolvimento_Body_B.step` | 1 | 1 | 16 | 263939,0 | -0.00..109.00 | — | — | — |
| `07_CAD_Matrizes/Matriz_Desenvolvimento_HISTORICA/MatrizDesenvolvimento_Canal_Fluxo.step` | 1 | 1 | 12 | 155370,4 | -0.00..109.00 | — | — | — |
| `07_CAD_Matrizes/Matriz_Desenvolvimento_HISTORICA/MatrizDesenvolvimento_Com_Fluxo.step` | 3 | 1/1/1 | 48 | 682946,8 | -0.00..109.00 | — | — | — |
| `07_CAD_Matrizes/Matriz_Desenvolvimento_HISTORICA/MatrizDesenvolvimento_Explodida.step` | 2 | 1/1 | 36 | 527576,4 | -0.00..109.00 | — | — | — |
| `07_CAD_Matrizes/Matriz_Gedeon_Certa/Cabecote_EX-030_com_Matriz_Gedeon_Certa.step` | 2 | 1/3 | 29 | 1250768,9 | -0.00..109.00 | — | — | — |
| `07_CAD_Matrizes/Matriz_Gedeon_Certa/MatrizGedeon_Certa_Body_A.step` | 1 | 1 | 19 | 320090,4 | -0.00..109.00 | — | — | — |
| `07_CAD_Matrizes/Matriz_Gedeon_Certa/MatrizGedeon_Certa_Body_B.step` | 1 | 1 | 19 | 320090,4 | -0.00..109.00 | — | — | — |
| `07_CAD_Matrizes/Matriz_Gedeon_Certa/MatrizGedeon_Certa_Canal_Fluxo.step` | 1 | 1 | 7 | 43017,9 | -0.00..109.00 | — | — | — |
| `07_CAD_Matrizes/Matriz_Gedeon_Certa/MatrizGedeon_Certa_Explodida.step` | 1 | 3 | 13 | 683198,6 | 0.00..109.00 | — | — | — |
| `07_CAD_Matrizes/Matriz_Gedeon_Certa/matrizGedeonCerta.step` | 1 | 3 | 18 | 640180,7 | -0.00..109.00 | 75.000×1.500 | Ø75.60 | Ø93.00 · Ø89.50 · Ø79.50 |
| `07_CAD_Matrizes/Matriz_Gedeon_Entregue_HISTORICA/MatrizGedeon.step` | 5 | 1/1/1/1/1 | 51 | 683248,4 | -0.00..109.00 | 75.000×1.500 | — | Ø93.00 · Ø89.50 · Ø79.50 |
| `07_CAD_Matrizes/Matriz_Gedeon_Entregue_HISTORICA/MatrizGedeon_Body_A.step` | 1 | 3 | 25 | 234332,8 | -0.00..109.00 | — | — | — |
| `07_CAD_Matrizes/Matriz_Gedeon_Entregue_HISTORICA/MatrizGedeon_Body_B.step` | 1 | 1 | 18 | 234823,9 | -0.00..109.00 | — | — | — |
| `07_CAD_Matrizes/Matriz_Gedeon_Entregue_HISTORICA/MatrizGedeon_Canal_Fluxo.step` | 1 | 1 | 14 | 213790,0 | -0.00..109.00 | — | — | — |
| `07_CAD_Matrizes/Matriz_Jonatha_v27_OFICIAL/MatrizJonatha.step` | 2 | 3/1 | 43 | 469001,7 | -0.00..109.00 | 75.000×1.500 | Ø75.60 | Ø93.00 · Ø89.50 · Ø79.50 |
| `07_CAD_Matrizes/Matriz_Jonatha_v27_OFICIAL/MatrizJonatha_Body_A.step` | 1 | 3 | 25 | 234255,3 | -0.00..109.00 | — | — | — |
| `07_CAD_Matrizes/Matriz_Jonatha_v27_OFICIAL/MatrizJonatha_Body_B.step` | 1 | 1 | 18 | 234746,4 | -0.00..109.00 | — | — | — |
| `07_CAD_Matrizes/Matriz_Jonatha_v27_OFICIAL/MatrizJonatha_Canal_Fluxo.step` | 3 | 1/1/1 | 23 | 214246,7 | -0.00..109.00 | — | — | — |
| `07_CAD_Matrizes/Matriz_Jonatha_v27_OFICIAL/MatrizJonatha_Com_Fluxo.step` | 5 | 3/1/1/1/1 | 66 | 683248,4 | -0.00..109.00 | — | — | — |
| `07_CAD_Matrizes/Matriz_Jonatha_v27_OFICIAL/MatrizJonatha_Explodida.step` | 2 | 3/1 | 43 | 469001,7 | -0.00..109.00 | — | — | — |
| `07_CAD_Matrizes/Matriz_Jonatha_v27_Peca_Unica/MatrizJonatha_v27_Peca_Unica.step` | 1 | 1 | 22 | 469303,2 | -0.00..109.00 | 75.000×1.500 | Ø75.60 | Ø93.00 · Ø89.50 · Ø79.50 |
| `07_CAD_Matrizes/Matriz_Jonatha_v28_1_PROPOSTA/MatrizJonatha_v28.step` | 2 | 1/1 | 82 | 456796,5 | -0.00..109.00 | 75.000×1.500 | Ø75.60 | Ø93.00 · Ø89.50 · Ø79.50 |
| `07_CAD_Matrizes/Matriz_Jonatha_v28_1_PROPOSTA/MatrizJonatha_v28_Body_A.step` | 1 | 1 | 39 | 228299,5 | -0.00..109.00 | — | — | — |
| `07_CAD_Matrizes/Matriz_Jonatha_v28_1_PROPOSTA/MatrizJonatha_v28_Body_B.step` | 1 | 1 | 43 | 228497,1 | -0.00..109.00 | — | — | — |
| `07_CAD_Matrizes/Matriz_Jonatha_v28_1_PROPOSTA/MatrizJonatha_v28_Canal_Fluxo.step` | 1 | 1 | 20 | 213945,1 | -0.00..109.00 | — | — | — |
| `07_CAD_Matrizes/Matriz_Jonatha_v28_1_PROPOSTA/MatrizJonatha_v28_Com_Fluxo.step` | 3 | 1/1/1 | 102 | 670741,7 | -0.00..109.00 | — | — | — |
| `07_CAD_Matrizes/Matriz_Jonatha_v28_1_PROPOSTA/MatrizJonatha_v28_Explodida.step` | 2 | 1/1 | 82 | 456796,5 | -0.00..109.00 | — | — | — |
| `07_CAD_Matrizes/Matriz_Jonatha_v28_1_PROPOSTA/MatrizJonatha_v28_Pinos_Alinhamento.step` | 4 | 1/1/1/1 | 12 | 1196,7 | 28.01..61.99 | — | — | — |

## O que divergiu

* C5 Cabecote_EX-030_com_Matriz_Jonatha_v28_1.step solido valido (BRepCheck) — tem solido invalido

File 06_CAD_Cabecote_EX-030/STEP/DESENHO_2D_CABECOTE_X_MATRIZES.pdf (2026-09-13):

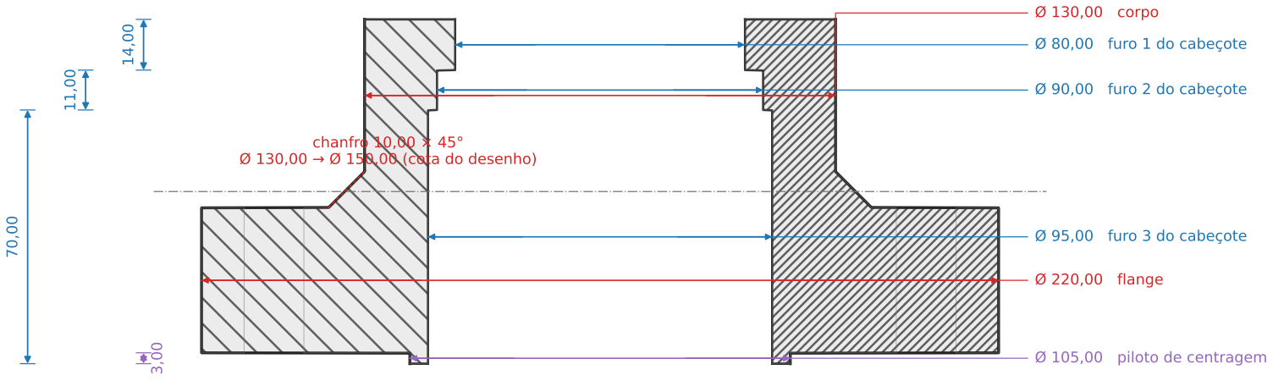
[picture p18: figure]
Ø 80,00 furo 1 do cabeçote; Ø 90,00 furo 2 do cabeçote; Ø 95,00 furo 3 do cabeçote; Ø 130,00 corpo; Ø 220,00 flange; Ø 105,00 piloto de centragem; chanfro 10,00 × 45°; Ø 150,00 (cota do desenho)

40,00 flange

95,00 comprimento total

geometria: seção do STEP `Cabecote_EX-030_desenhado.step` (arestas reais, cinza fino) e perfil de corte medido dele fatia a fatia (preto, hachurado). Z = 0 no plano mais traseiro da peça; face do nariz em Z = 95,00. Cotas: `cabecote_ex030.json` e `verificar_interface_cabecote.py` - os mesmos dados com que este STEP foi construído. Não aparecem neste corte por acaso do plano, não por omissão: as 6 fendas do flange e os 6 × Ø16,50 (M12) em C.C. Ø180,00.

1 CABEÇOTE EX-030 | vista lateral em corte pelo plano do eixo

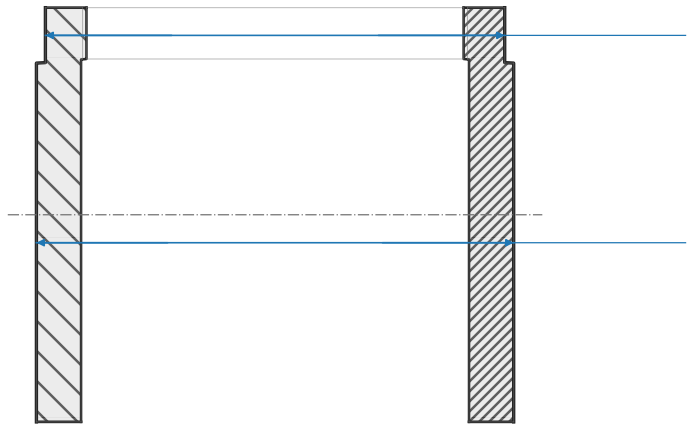
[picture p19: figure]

Ø 93,00 estágio 1 (Z 0,00 | 69,80)
Ø 89,50 estágio 2 (Z 70,00 | 80,60)

69,80

10,60

69,909 banda até o ombro

80,70 comprimento da matriz

geometria e cotas: seção e escada medidas no STEP `Matriz1_Original_Copo_Solido.step` (aberto só para leitura; `02_CAD_Modelos_Historicos/` não é modificado - regra 2), publicadas em `perfis_matrizes_x_cabecote.json`. A peça é de corpo único. Corte feito no plano Y = 0 (plano do eixo) - em peça bipartida o plano Y = 0 é o de partição, onde não há seção, há a face
de junção das metades. O canal medido nesta seção: Ø 75,60 mm (aparece como faixa vazia). Ø máx medido 93,00; comprimento 80,70;
ombro (fim da banda) em Z = 70,00.
2 Matriz 1 - Copo (original, a que o cabecote foi feito em volta) | vista lateral em corte pelo plano do eixo
Ø 93,00 estágio 1 (Z 0,00 | 69,80)
Ø 89,50 estágio 2 (Z 70,00 | 80,60)
Ø 79,50 estágio 3 (Z 80,80 | 109,00)

69,80

10,60

28,20

69,909 banda até o ombro

109,00 comprimento da matriz

3 Matriz 2 - Gedeon (a maior, que o usuario diz que entra) vista lateral em corte pelo plano do eixo

14,30 saída da matriz DENTRO da face do nariz

80,70 matriz dentro do bolso

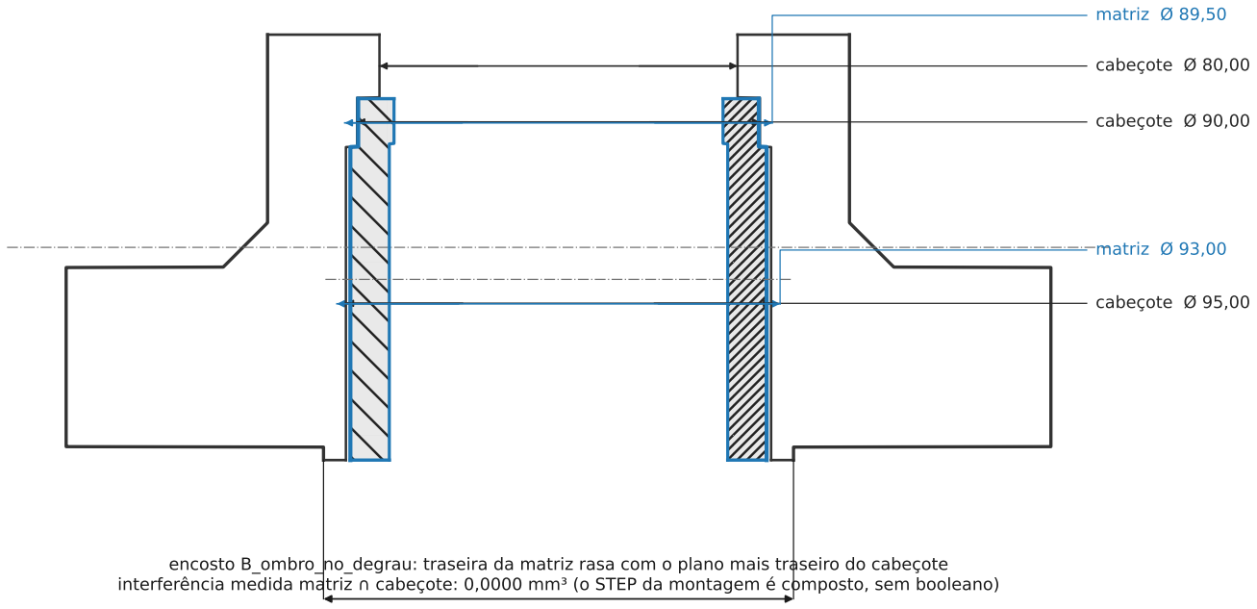
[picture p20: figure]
cabeçote Ø 80,00; cabeçote Ø 90,00; cabeçote Ø 95,00; matriz Ø 93,00; matriz Ø 89,50

encosto B_ombro_no_degrau: traseira da matriz rasa com o plano mais traseiro do cabeçote interferência medida matriz cabeçote: 0,0000 mm³ (o STEP da montagem é composto, sem booleano)

posição axial definida pelo cabeçote (degrau + fundo do bolso), não pela máquina: folga radial banda bolso 1,000 mm e folga axial no
degrau 0,091 mm; encosto usado = `B_ombro_no_degrau` (deslocamento 0,00 mm). Saída da matriz em Z = 80,70, ou 14,30 para dentro da face do nariz (95,00).
Cada número desta faixa é medido nos dois STEP - cabeçote cortado em Y = 0 (plano do eixo), matriz em Y = 0 (plano do eixo). A matriz por `02_CAD_Modelos_Historicos/Matriz1_Original_Copo_Solido.step`, o assento por
`medir_perfis_matrizes_x_cabecote.py`.
A seccao e tomada na uniao A U B, que conserva as cavidades internas seladas do Body_A (1 solido com 3 cascas no arquivo de origem) - e por isso elas aparecem no desenho. O STEP da montagem entregue entrega as metades separadas, sem booleano (`cabecote_step.json:inventario_dos_arquivos_de_matriz`). Os Ø aqui são os MEDIDOS no STEP da peça - no DXF a banda da matriz coincide com o bolso Ø95 e o canal é desenhado com 17,00 mm
(versus os 11,00 mm do furo): ver `cabecote_ex030.json:matriz_copo_desenhada_no_dxf`.

1 MONTAGEM Matriz 1 - Copo: cabeçote (contorno) + matriz (azul, hachurada), mesmo referencial axial

14,00 saída da matriz FORA da face do nariz

95,00 matriz dentro do bolso

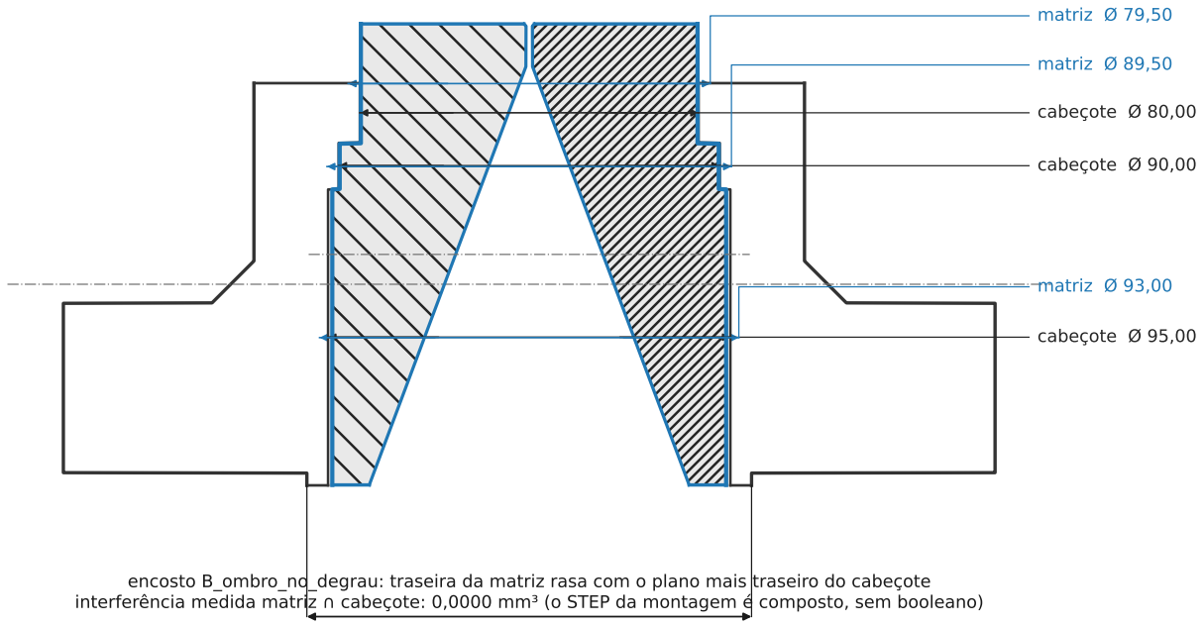
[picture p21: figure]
cabeçote Ø 80,00; cabeçote Ø 90,00; cabeçote Ø 95,00; matriz Ø 93,00; matriz Ø 89,50; matriz Ø 79,50

encosto B_ombro_no_degrau: traseira da matriz rasa com o plano mais | traseiro do cabeçote
interferência medida matriz | cabeçote: 0,0000 mm³ (o STEP da montagem é | composto, sem booleano)
2 MONTAGEM | Matriz 2 - Gedeon: cabeçote (contorno) + matriz (azul, hachurada), mesmo referencial axial

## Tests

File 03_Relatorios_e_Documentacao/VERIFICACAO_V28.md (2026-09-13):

# Verificação exata da revisão v28.1 — Matriz Jonatha

Medida nos STEP gerados por `gerar_matriz_v28.py` (booleanos + BRepExtrema; nada é estimado).

**64 itens verificados · 64 conformes · 0 não conformes**

| Item | Nominal | Medido | Status | Observação |
| :--- | ---: | ---: | :---: | :--- |
| Canal entregue com 1 único sólido (o v27 tinha 3) | — | 1 sólido(s) | ✅ | necessário p/ eletrodo de EDM e malha de CFD |
| Comprimento total Z | 109 | 109 | ✅ |  |
| Ø externo máximo (estágio 1) | 93 | 93 | ✅ |  |
| Ø externo em Z=0,500 (estágio Ø93,0) | 93 | 93 | ✅ |  |
| Ø externo em Z=75,300 (estágio Ø89,5) | 89,5 | 89,5 | ✅ |  |
| Ø externo em Z=94,850 (estágio Ø79,5) | 79,5 | 79,5 | ✅ |  |
| Ø da boca de entrada (Z=0) | 75,6 | 75,6 | ✅ |  |
| Largura da fenda (X) | 75 | 75 | ✅ |  |
| Espessura da fenda (Y) | 1,5 | 1,5 | ✅ |  |
| Área da seção da fenda (R0,75 nas bordas) | 112,017 | 112,017 | ✅ |  |
| Funil (Z<99) geometricamente idêntico ao master v27.0 | — | Δmáx entre superfícies = 0,000000 mm | ✅ | a revisão não mexe no aprovado |
| Volume do funil v28 vs v27 | — | diferença = 0,0278 mm³ | ✅ | mesmo sólido abaixo de Z=99 |
| Assimetria do canal em torno do plano de partição Y=0 | — | |A-B| = 199,22 mm³ (0,093 % do canal) | ✅ | herdado do loft do v27.0: as metades não são espelhos exatos |
| Arquivos STEP entregues (nomes + nº de sólidos) | — | 7/7 exatos | ✅ | mestr=2 · explodida=2 · com_fluxo=3 · pinos=4 · canal=1 · corpo=1 |
| Land reto e paralelo (v27.0: 8,50) | 8,5 | 8,5 | ✅ | P8 resolvido no modelo |
| Chanfro de saída (v27.0: 1,50) | 1,5 | 1,5 | ✅ | D2: lábio mantido como no master, sem ganho de land |
| Sobrelargura do chanfro a 0,10 mm da face | 1,4 | 1,402 | ✅ | chanfro de 45° |
| Lâmina de aço no lábio de saída (= valor decidido em D2) | 0,75 | 0,75 | ✅ | a decisão D2 aceitou a lâmina fina de 0,75 mm do master; o lascamento na limpeza passa a ser item de procedimento de manutenção, não de geometria |
| Shells no Body_A (v27.0 tinha 3 = 2 bolhas seladas) | — | 1 | ✅ | 1 = sólido limpo, sem cavidade interna |
| Shells no Body_B (v27.0 tinha 1, mas sem furo nenhum) | — | 1 | ✅ | 1 = sólido limpo |
| Interferência Body_A ∩ Body_B | 0 | 0 | ✅ |  |
| Pino em X=-42.10 Z=30.00 | — | A: bolso vazio 0.0000 mm³, aço sob o fundo 12.6/12.6 mm³ | B: 0.0000 / 12.6 mm³ | ✅ | aberto no plano de partição e cego sob o fundo nas DUAS metades |
| Pino em X=+42.10 Z=30.00 | — | A: bolso vazio 0.0000 mm³, aço sob o fundo 12.6/12.6 mm³ | B: 0.0000 / 12.6 mm³ | ✅ | aberto no plano de partição e cego sob o fundo nas DUAS metades |
| Pino em X=-42.10 Z=60.00 | — | A: bolso vazio 0.0000 mm³, aço sob o fundo 12.6/12.6 mm³ | B: 0.0000 / 12.6 mm³ | ✅ | aberto no plano de partição e cego sob o fundo nas DUAS metades |
| Pino em X=+42.10 Z=60.00 | — | A: bolso vazio 0.0000 mm³, aço sob o fundo 12.6/12.6 mm³ | B: 0.0000 / 12.6 mm³ | ✅ | aberto no plano de partição e cego sob o fundo nas DUAS metades |
| Pinos conjugados nas duas metades | — | 4/4 no Body_A e 4/4 no Body_B | ✅ | v27.0: bolsões selados só no A e nada no B (P2) |
| Fechamento: env − (aço + canal) = volume dos furos | 12506,7 | 12506,7 | ✅ | prova que todo furo removido existe no corpo e nada mais foi tirado |
| parede mínima até o canal - pino_alinhamento X=-42.10 Z=30.00 | — | 2,391 mm | ✅ | alvo ≥ 2,00 mm | invadiu o canal em 0,000000 mm³ |
| ∩ volume do canal - pino_alinhamento X=-42.10 Z=30.00 | — | 0,000000 mm³ | ✅ | zero = o furo não comunica com o fluxo |
| parede mínima até o canal - pino_alinhamento X=+42.10 Z=30.00 | — | 2,392 mm | ✅ | alvo ≥ 2,00 mm | invadiu o canal em 0,000000 mm³ |
| ∩ volume do canal - pino_alinhamento X=+42.10 Z=30.00 | — | 0,000000 mm³ | ✅ | zero = o furo não comunica com o fluxo |
| parede mínima até o canal - pino_alinhamento X=-42.10 Z=60.00 | — | 2,482 mm | ✅ | alvo ≥ 2,00 mm | invadiu o canal em 0,000000 mm³ |
| ∩ volume do canal - pino_alinhamento X=-42.10 Z=60.00 | — | 0,000000 mm³ | ✅ | zero = o furo não comunica com o fluxo |
| parede mínima até o canal - pino_alinhamento X=+42.10 Z=60.00 | — | 2,483 mm | ✅ | alvo ≥ 2,00 mm | invadiu o canal em 0,000000 mm³ |
| ∩ volume do canal - pino_alinhamento X=+42.10 Z=60.00 | — | 0,000000 mm³ | ✅ | zero = o furo não comunica com o fluxo |
| parede mínima até o canal - cartucho X=+0.00 Z=97.00 | — | 8,196 mm | ✅ | alvo ≥ 4,00 mm | invadiu o canal em 0,000000 mm³ |
| ∩ volume do canal - cartucho X=+0.00 Z=97.00 | — | 0,000000 mm³ | ✅ | zero = o furo não comunica com o fluxo |
| parede mínima até o canal - cartucho X=+0.00 Z=97.00 | — | 8,196 mm | ✅ | alvo ≥ 4,00 mm | invadiu o canal em 0,000000 mm³ |
| ∩ volume do canal - cartucho X=+0.00 Z=97.00 | — | 0,000000 mm³ | ✅ | zero = o furo não comunica com o fluxo |
| parede mínima até o canal - cartucho X=-22.00 Z=97.00 | — | 9,313 mm | ✅ | alvo ≥ 4,00 mm | invadiu o canal em 0,000000 mm³ |
| ∩ volume do canal - cartucho X=-22.00 Z=97.00 | — | 0,000000 mm³ | ✅ | zero = o furo não comunica com o fluxo |
| parede mínima até o canal - cartucho X=-22.00 Z=97.00 | — | 9,324 mm | ✅ | alvo ≥ 4,00 mm | invadiu o canal em 0,000000 mm³ |
| ∩ volume do canal - cartucho X=-22.00 Z=97.00 | — | 0,000000 mm³ | ✅ | zero = o furo não comunica com o fluxo |
| parede mínima até o canal - cartucho X=+22.00 Z=97.00 | — | 9,356 mm | ✅ | alvo ≥ 4,00 mm | invadiu o canal em 0,000000 mm³ |
| ∩ volume do canal - cartucho X=+22.00 Z=97.00 | — | 0,000000 mm³ | ✅ | zero = o furo não comunica com o fluxo |
| parede mínima até o canal - cartucho X=+22.00 Z=97.00 | — | 9,324 mm | ✅ | alvo ≥ 4,00 mm | invadiu o canal em 0,000000 mm³ |
| ∩ volume do canal - cartucho X=+22.00 Z=97.00 | — | 0,000000 mm³ | ✅ | zero = o furo não comunica com o fluxo |
| parede mínima até o canal - termopar X=-11.00 Z=103.00 | — | 16,349 mm | ✅ | alvo ≥ 3,00 mm | invadiu o canal em 0,000000 mm³ |
| ∩ volume do canal - termopar X=-11.00 Z=103.00 | — | 0,000000 mm³ | ✅ | zero = o furo não comunica com o fluxo |
| parede mínima até o canal - termopar X=-11.00 Z=103.00 | — | 16,349 mm | ✅ | alvo ≥ 3,00 mm | invadiu o canal em 0,000000 mm³ |
| ∩ volume do canal - termopar X=-11.00 Z=103.00 | — | 0,000000 mm³ | ✅ | zero = o furo não comunica com o fluxo |
| parede mínima até o canal - termopar X=+11.00 Z=103.00 | — | 16,349 mm | ✅ | alvo ≥ 3,00 mm | invadiu o canal em 0,000000 mm³ |
| ∩ volume do canal - termopar X=+11.00 Z=103.00 | — | 0,000000 mm³ | ✅ | zero = o furo não comunica com o fluxo |
| parede mínima até o canal - termopar X=+11.00 Z=103.00 | — | 16,349 mm | ✅ | alvo ≥ 3,00 mm | invadiu o canal em 0,000000 mm³ |
| ∩ volume do canal - termopar X=+11.00 Z=103.00 | — | 0,000000 mm³ | ✅ | zero = o furo não comunica com o fluxo |
| Furos de aquecimento: abertos na face externa, cegos, sem romper as faces | — | OK - todos os 14 | ✅ | atravessar a peça = vazamento; ficar enterrado = não usinável |
| Menor web de aço entre dois furos | — | 5,380 mm | ✅ | par: cartucho X=+0.0 Z=97.0 × termopar X=-11.0 Z=103.0 | mínimo 3.00 mm |
| Massa de aço (7,85 g/cm³) | — | 3,586 kg | ✅ | v27.0: 3,682 kg | aços: P20 pré / H13 temperado |
| Área projetada do canal no plano XZ (medida) | — | 8169 mm² | ✅ | é a área sobre a qual a pressão empurra as metades uma contra a outra |
| Força que abre a bipartição | — | 55,7 kN no limite (pressão plena em toda a área) · 30,6 kN sobre a boca Ø75,60 | ✅ | por isso a fixação não é opcional (ver relatório DFM) |
| ΔP 1D - lei das potências (método do próprio projeto) | — | v28.1 = 26,6 bar | v27.0 = 26,6 bar | ✅ | land 8,50 vs 8,50 paralelos → -0.0 bar; maior gradiente em Z≈99,2 mm |
| τ na parede do land | — | 163,8 kPa (γ̇_ap = 911 s⁻¹) | ✅ | não depende do comprimento do land: mesma fenda, mesma vazão |
| Faixa de aço entre o canal e o Ø93 | — | 8.70 mm | ✅ | sem espaço para furo de pressão: Ø9,5 + parede 4 + parede 4 = 11,5 mm |
| Cotas de usinagem do land | — | paralelo Z=99,00→107,50 mm (8,50) · chanfro 1,50×45° Z=107,50→109,00 mm | ✅ | conferir no desenho antes de cortar o aço |

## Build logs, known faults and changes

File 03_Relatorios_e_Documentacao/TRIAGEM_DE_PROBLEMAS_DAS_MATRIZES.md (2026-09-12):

# TRIAGEM DAS MATRIZES — O QUE É PROBLEMA REAL E O QUE NÃO É

**Projeto:** Matrizes de extrusão plana de manta isolante MT — Matriz 1 (Copo), Matriz 2 (Gedeon), Matriz Desenvolvimento e Matriz Jonatha v27 (oficial)
**Data:** 11 de setembro de 2026
**Método:** medição direta das seções e volumes dentro dos arquivos STEP — não a leitura dos relatórios. Cada afirmação abaixo traz a medida e o arquivo de origem. Scripts: `04_Dados_SSOT_e_Scripts/verify_geometry_ssot.py` (matriz oficial) e `verify_legacy_dies.py` (as quatro matrizes).

> **Resumo em uma frase:** os problemas reais da Matriz Jonatha são de **fabricação** (fixação, pinos e controle térmico inexistentes) e de **entrega** (um arquivo de canal errado e números de CFD não reproduzíveis); a geometria do canal aprovado — envelope, funil, land e fenda — **está correta e é melhor que a da Matriz 2 de fato**, o que ficou comprovado por medição.

---

## 1. O que cada matriz realmente é (medido nos STEP)

| | **Matriz 1 — Copo** | **Matriz 2 — Gedeon** | **Matriz Desenvolvimento** | **Matriz Jonatha v27** |
| :--- | :--- | :--- | :--- | :--- |
| Comprimento / envelope | Ø93 × 80,70 mm (só 2 estágios) | Ø93 × 69,9 + Ø89,5 × 10,8 + Ø79,5 × 28,3 = 109 mm | idem Matriz 2 | idem Matriz 2 |
| Entrada (Z=0) | disco Ø75,60 | disco Ø75,57 que já em Z=1 tem 75,0 × 72,1 | retângulo 75,0 × 40,0 | disco Ø75,60 |
| Funil de distribuição | **não existe** (degrau de 90°) | **21,0 mm** (de 74 mm para 1,5 mm) | 99,0 mm linear | 99,0 mm linear |
| Land (fenda 75 × 1,5) | 9,95 mm | **88,00 mm** | 10,00 mm | 10,00 mm (8,50 paralelos + 1,50 de chanfro) |
| Canal de polímero (real) | 318.480 mm³ | 43.018 mm³ | 155.370 mm³ | 213.945 mm³ |
| Arquivo "Canal_Fluxo" × corpo | ✅ confere | ❌ **4,96× maior** | ✅ confere | ✅ confere |
| Pinos de alinhamento | (não tem) | Ø1,78 × 10 mm atravessando as duas metades | — | 2 furos Ø4 × 12, só no `Body_A`, **selados** |
| ΔP por lei das potências (1D, medido) | 23,8 bar | **194,2 bar** | 31,3 bar | **26,6 bar** |
| ΔP declarado no relatório | 185,4 bar | 268,7 bar | — | 68,2 bar |
| Razão medido/declarado | 0,13× ❌ | 0,72× | — | 0,39× ❌ |

Cálculo próprio: lei das potências com **K = 18.500 Pa·s^n, n = 0,32, Q = 15 cm³/s** (os mesmos parâmetros do SSOT), integrada sobre a geometria medida. É um modelo 1D de escoamento desenvolvido: válido para comparar matrizes e checar ordem de grandeza, **não** substitui CFD.

> **Correção de 11/09/2026** — a fórmula da fenda larga usada na primeira versão desta tabela tinha um fator extra `(1+n)/n`, que inflava o ΔP em `((1+n)/n)^n = 1,573×`. Valores antigos (37,1 / 305,5 / 49,3 / 41,9 bar) foram substituídos pelos corretos (23,8 / 194,2 / 31,3 / 26,6 bar). O fator de correção foi verificado contra o CFD 2D da seção do land da Jonatha: **2,1761 bar/mm** medidos no CFD contra **2,19 bar/mm** na fórmula — 0,6%. A razão medido/declarado da Jonatha passa de 0,61× para 0,39×, ou seja, o ΔP do canal é **ainda menor** do que se supunha, e a folga da extrusora é maior.

---

## 2. 🔴 PROBLEMAS REAIS

### P1 — A Matriz Jonatha não tem nenhum meio de fixação · **BLOQUEADOR DE FABRICAÇÃO**

**Medido:** 0 furos de fixação/aperto no `Body_A` e no `Body_B` (os únicos furos usinados são os de pino).

**Por que é problema:** com 68,2 bar dentro do canal, a força que empurra as duas metades uma contra a outra é da ordem de **30 kN (≈3,1 tf)** — pressão de 6,82 MPa × área projetada da cavidade no plano de partição (≈4.489 mm², a seção da entrada). Sem parafusos ou grampos, a matriz **abre no plano Y=0** durante o trabalho: sai rebarba no meio da manta, vaza polímero e a espessura de 1,50 mm perde controle.

**Restrição geométrica (medida):** entre a parede do canal e a superfície externa sobram só **1,9 mm** de aço na região do pino e ~2,2 mm perto do land; o 3º estágio é Ø79,5. Por isso **não há espaço para parafusos axiais** atravessando o corpo: a fixação M8 tem de ser radial (em Y), nas asas do Ø93, com rebaixo (spot face) na superfície cilíndrica — ou por grampos/quadro externo.

---

### P2 — Os pinos de alinhamento não existem de verdade · **BLOQUEADOR DE MONTAGEM**

**Medido no `MatrizJonatha_Body_A.step`:** o sólido tem **3 shells** (1 externo + 2 cavidades internas). Cada "furo" Ø4 × 12 é formado por **duas tampas planas de 12,566 mm²** (em Y = 0 e Y = −12) mais uma face cilíndrica de 150,796 mm² — ou seja, é uma **bolha fechada dentro do aço**, invisível em qualquer visualizador e impossível de usinar.

**E o `Body_B` tem 1 shell: nenhum furo.**

**Impacto:** as metades não têm referência de alinhamento. O plano de partição pode deslocar lateralmente e criar degrau/rebarba no meio da manta justamente na espessura mais crítica (1,5 mm).

**Comparação com a Matriz 2:** nela o pino atravessa as duas metades — sólido medido de 24,88 mm³ = **Ø1,78 × 10 mm** em X = ±41,50, Z = 54,50 a 64,50. Ou seja, a Jonatha **regrediu** exatamente no item que a Matriz 2 acertava.

**Ação:** refazer os furos nos dois corpos, com a mesma referência (X = ±41,50, Z = 54,50), Ø4 H7 × 12 mm cegos em cada metade, e usar 2 pinos Ø4 × 20 mm temperados.

---

### P3 — Sem controle térmico · **RISCO DE REPETIR O DEFEITO QUE ORIGINOU O PROJETO**

**Medido:** 0 furos para cartucho de resistência Ø9,5; 0 poço de termopar; 0 canais de refrigeração.

**Por que é problema:** os próprios relatórios do projeto dizem que o rasgo de borda (*edge tearing*) aparece quando a matriz esquenta — porque a resistência do fundido cai. Sem controle térmico, a matriz acompanha passivamente a temperatura do canhão e a janela de 50–65 °C não fica garantida ao longo do turno.

**Ação:** acrescentar no CAD **antes** da têmpera/nitretação. Depois disso, furar aço a 52 HRC é caro e arriscado.

---

### P4 — Sem padrão de acoplamento na face Z=0 · **DEPENDE DE DADO EXTERNO**

**Medido:** nenhum furo na face traseira; o assentamento é apenas o encaixe Ø75,60.

**Ação:** extrair o padrão de furos do cabeçote original (`030-032- cabeçote.dwg`) ou medir o flange na máquina. Sem esse dado, qualquer flange projetado é palpite.

---

### P5 — O arquivo `MatrizGedeon_Canal_Fluxo.step` está errado · **RISCO DE ENGENHARIA / EDM**

**Medido:** o arquivo tem **213.790,03 mm³**, mas o vazio real da Matriz 2 é **43.017,90 mm³** (medido dentro da própria montagem `MatrizGedeon.step`) — **4,96 vezes menor**. E o pior: as seções do arquivo são **idênticas às da Matriz Jonatha** (boca Ø75,6, funil que chega na fenda em Z = 99). O arquivo descreve outro canal, não o da Matriz 2.

**Impacto:** qualquer CFD, eletrodo de EDM ou análise feita sobre esse arquivo não representa a Matriz 2. Se alguém comparar "antes × depois" usando esse arquivo, os dois canais ficam iguais e a melhoria desaparece da análise.

**Ação:** reexportar o canal da Matriz 2 a partir do sólido real da montagem (o script `verify_legacy_dies.py` já o identifica automaticamente) ou marcar o arquivo como inválido no repositório.

---

### P6 — Os números de CFD não são reproduzíveis · **RISCO DE DECISÃO**

Recalculado com os **mesmos parâmetros reológicos do SSOT** sobre a geometria medida:

| Alegação | Medição independente | Veredito |
| :--- | :--- | :--- |
| Matriz 2: ΔP = 268,7 bar | 194,2 bar | ⚠️ mesma ordem (0,72×), mas o declarado é 38% maior |
| Jonatha: ΔP = 68,2 bar | 26,6 bar | ❌ 0,39×: o declarado é 2,6× o medido |
| Matriz 1: ΔP = 185,4 bar | 23,8 bar | ❌ 0,13× — o 1D não captura a contração de 90°, que é o defeito real dela; esse número não sai do método declarado |
| τ na parede: Gedeon 157,11 kPa → Jonatha 128,44 kPa | **164,0 kPa nas duas** (γ̇ = 915 s⁻¹) | ❌ impossível: o land é o **mesmo** (75 × 1,5) e a vazão é a **mesma** — a tensão de cisalhamento na parede não pode diferir entre as duas |
| Uniformidade 99,10% / 68,96% / 54,73% | — | ⚠️ não auditável: não existe definição (variação de quê, medida onde) nem planilha no repositório |

**O que é verdade na física:** a direção do ganho é correta e comprovável. A Matriz 2 comprime o fluxo de 74 mm para 1,5 mm em 21 mm (funil quase cego) e depois o mantém 88 mm num land fino; a Jonatha faz a mesma compressão em 99 mm e mantém apenas 8,5 mm de land. Como a perda de carga no land é proporcional ao comprimento, a diferença medida (194,2 → 26,6 bar) é explicada por geometria, não por narrativa.

**Ação:** refazer os números em script versionado (ou rotular os atuais como "estimativa a confirmar"). O número de 99,10% precisa de definição explícita antes de ser usado como critério de aceitação.

---

### P7 — Lábio de saída com 0,75 mm de aço · **RISCO DE ROBUSTEZ (decisão de engenharia)**

**Medido:** no plano Z = 109 a face é um anel Ø79,5 cuja abertura já é 78,0 × 4,5 (o chanfro de 1,5 × 45°). Sobram **0,75 mm de aço** de cada lado.

**Não é problema de escoamento** (nessa região a pressão já caiu para a atmosfera), mas é uma lâmina frágil: risco de lascar na limpeza ou no transporte, e impossível de refacear plana depois.

**Ação sugerida:** chanfro de **0,8 mm × 45°** → lábio de ≈1,45 mm e land paralelo subindo de 8,50 para ≈9,20 mm (as duas coisas boas ao mesmo tempo).

---

### P8 — Documentação: o land não tem 10 mm paralelos · **CORREÇÃO DE SSOT**

**Medido:** o chanfro ocupa Z = 107,50 a 109,00; logo o **land reto e paralelo é 8,50 mm**, e não os 10,00 mm que constam no SSOT. Em escoamento isso vale ≈6 bar (≈9%) — não muda a aprovação —, mas quebra a rastreabilidade: qualquer verificação futura vai acusar divergência.

**Ação:** corrigir o SSOT para "8,50 mm paralelos + 1,50 mm de chanfro" (ou reduzir o chanfro conforme P7).

---

## 3. 🟢 O QUE NÃO É PROBLEMA (verificado e aprovado)

| # | Item | Evidência da medição |
| :--: | :--- | :--- |
| **N1** | Envelope externo escalonado (Ø93 × 69,90 / Ø89,50 × 10,80 / Ø79,50 × 28,30; Z = 109,000) | Medido na Jonatha **e** na Matriz 2: são iguais. A compatibilidade de montagem na máquina está comprovada. |
| **N2** | Fenda 75,00 × 1,50 com bordas semicirculares R0,75 | Área medida 112,017 mm² — exatamente o valor analítico `(75 − 1,5) × 1,5 + π × 0,75²`. O arquivo é fiel à especificação. |
| **N3** | Desenho do canal da Jonatha (nada de arestas frágeis ou paredes de espessura zero na entrada) | Varredura seção a seção: a boca Ø75,60 é o **envelope máximo** do canal e todas as seções seguintes ficam dentro dela — o aço em volta é contínuo. |
| **N4** | Bipartição em Y = 0 | Interferência 0,000 mm³; `aço + canal + furos` fecham o envelope com **0,001 mm³** de resíduo. |
| **N5** | Volumes e massa | Body_A 234.255,29 mm³, Body_B 234.746,37 mm³, canal 213.945,15 mm³ → **3,682 kg** de aço. Bate com o SSOT na casa dos milésimos. |
| **N6** | Consistência dos arquivos entregues | Matriz 1, Matriz Desenvolvimento e Matriz Jonatha têm o "canal isolado" igual ao vazio do corpo. **Só** o da Matriz 2 está errado (P5). |
| **N7** | A Matriz 1 não perdia carga por atrito | O trecho reto Ø75,6 mais os ~10 mm de fenda dão ≈24 bar em 1D — praticamente o mesmo da Jonatha (26,6 bar). O defeito dela é o **degrau de 90°** (parede cega que rasga o fundido), e não "185,4 bar de contrapressão". A troca da matriz continua certa; o motivo apontado nos relatórios é que estava errado. |
| **N8** | O ganho da Jonatha sobre a Matriz 2 é real | Land medido: **88,0 mm → 8,5 mm**. Perda de carga medida: **194,2 → 26,6 bar**. A redução declarada (268,7 → 68,2 bar) é **conservadora** em relação à medição — o ganho não é marketing, é geometria. |

---

## 4. 🟡 O QUE PRECISA SER REFAZER (alegações que não se sustentam)

| Alegação nos relatórios | O que a medição mostra | Ação |
| :--- | :--- | :--- |
| "τ na parede cai de 157,11 para 128,44 kPa" | Seção do land e vazão idênticas ⇒ τ é o mesmo nas duas: **164,0 kPa** | Recalcular; o ganho real está no ΔP, não em τ |
| "Matriz 1: 185,4 bar / 54,73% de uniformidade" | 1D sobre a geometria medida dá **23,8 bar** (o degrau de 90° não é capturado por 1D) | Se o número for necessário, rodar CFD 2D/3D de verdade; senão, marcar como não verificado |
| "Uniformidade de 99,10%" | Sem definição nem planilha no repositório | Publicar a definição (variação de quê, medida em qual plano) e o cálculo |
| "Land: 87,60 → 10,00 mm (−88,6%)" | Medido **88,0 → 10,0 mm** ✅, mas o "10,00" inclui 1,50 mm de chanfro ⇒ paralelos = 8,50 mm | Confirmar o ganho e corrigir o valor do land paralelo (P8) |

---

## 5. Plano de ação priorizado (antes de cortar o aço)

| Prioridade | Ação | Motivo | Observação de custo |
| :--: | :--- | :--- | :--- |
| **1** | Definir e usinar a fixação (M8 radial nas asas com spot face, ou grampos externos) | P1 | barato agora, retrabalho caro depois da têmpera |
| **2** | Refazer os furos de pino nos **dois** corpos e providenciar os pinos | P2 | idem |
| **3** | Furação térmica: cartuchos Ø9,5, termopar, 2 canais de refrigeração Ø8 por metade | P3 | idem |
| **4** | Corrigir os arquivos: reexportar o canal da Matriz 2 e deixar o canal da Jonatha com 1 sólido | P5 | sem custo de usinagem |
| **5** | Decidir chanfro/lábio (0,8 × 45°) e atualizar o SSOT (land 8,50 paralelos) | P7 / P8 | decisão de engenharia |
| **6** | Refazer os números reológicos em script versionado e definir "uniformidade" | P6 | ~1 dia de trabalho |
| **7** | Flange de entrada (aguarda DWG do cabeçote ou medição na máquina) | P4 | depende de dado externo |

---

## 6. Como reproduzir esta triagem

```bash
bash 04_Dados_SSOT_e_Scripts/setup_headless_gl.sh
export LD_LIBRARY_PATH="$PWD/04_Dados_SSOT_e_Scripts/.headless_gl:$LD_LIBRARY_PATH"

# 1) Matriz oficial: 34 checagens dimensionais contra o SSOT
python 04_Dados_SSOT_e_Scripts/verify_geometry_ssot.py --json --md

# 2) As quatro matrizes: envelope, entrada, funil, land, consistência dos arquivos e ΔP 1D
python 04_Dados_SSOT_e_Scripts/verify_legacy_dies.py --json
```

Saídas: `04_Dados_SSOT_e_Scripts/auditoria_geometrica.json`, `auditoria_matrizes_historicas.json` e `03_Relatorios_e_Documentacao/AUDITORIA_GEOMETRICA_MATRIZ_JONATHA.md`.

---

*Documento gerado a partir de medições nos arquivos STEP em 11/09/2026. Os valores marcados como ❌ ou ⚠️ devem ser refeitos antes de qualquer decisão de investimento.*

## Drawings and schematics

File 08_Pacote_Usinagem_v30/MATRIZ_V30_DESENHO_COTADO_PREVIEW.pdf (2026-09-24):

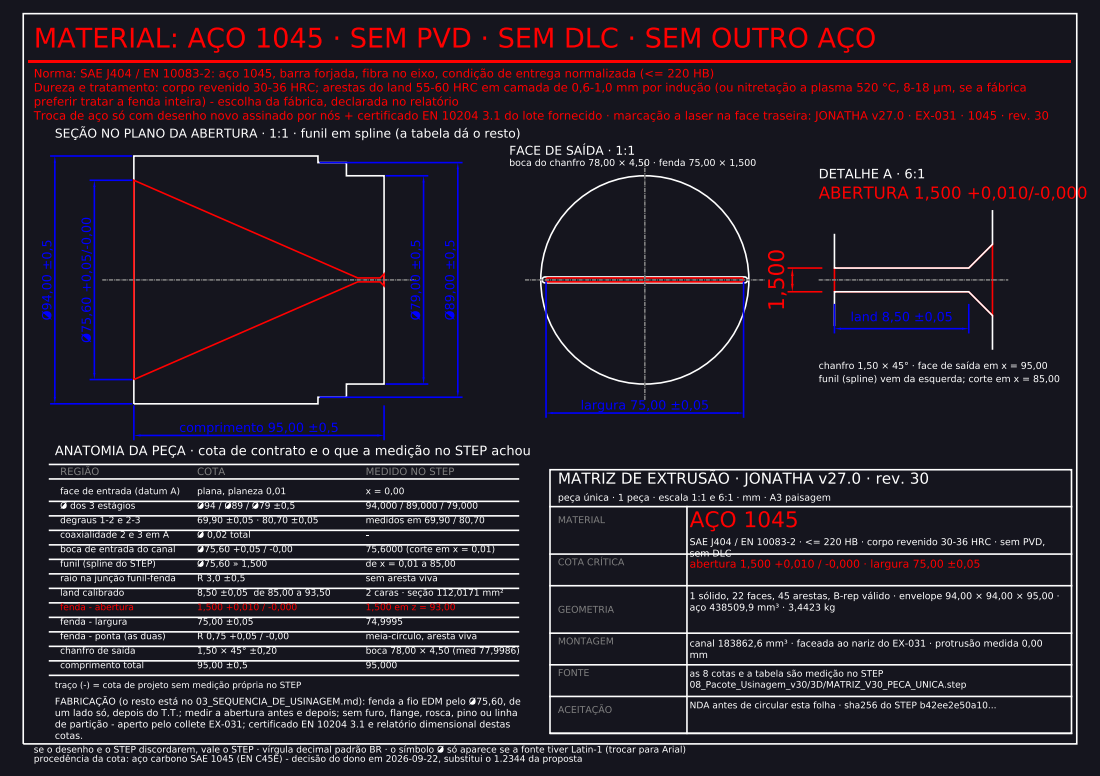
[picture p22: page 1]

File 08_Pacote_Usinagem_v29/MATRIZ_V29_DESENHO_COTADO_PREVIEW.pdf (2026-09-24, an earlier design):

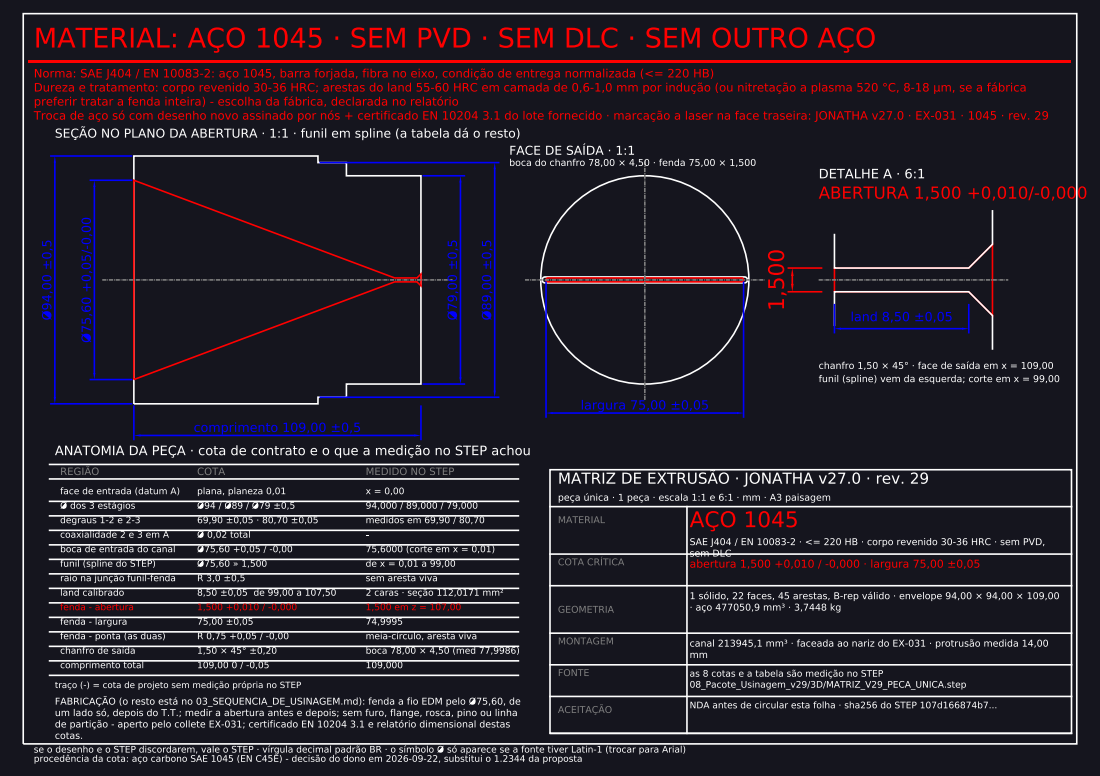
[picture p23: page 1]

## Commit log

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2026-09-11 Organize workspace into categorized folders (< 24MB per folder) and remove uploads
    [Matriz1_Original_Copo.step, Matriz1_Original_Copo_Body_A.step, Matriz1_Original_Copo_Body_B.step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]
2026-09-11 Resolve critical audit pendency A-01: Verify 3D geometry Hm=12.00mm, Delta P=39.5 bar v26.1
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2026-09-11 Triagem das 4 matrizes: separa problema real de alegacao nao sustentada
    - verify_legacy_dies.py: mede as 4 matrizes (envelope, entrada, funil, land),
    confere o canal isolado contra o vazio real do corpo e recalcula o dP por
    lei das potencias sobre a geometria medida
    - TRIAGEM_DE_PROBLEMAS_DAS_MATRIZES.md: P1..P8 (problemas reais), N1..N8
    (nao-problemas verificados) e as alegacoes a refazer
    - P5: MatrizGedeon_Canal_Fluxo.step tem 4,96x o volume do canal real
    - P2: furos de pino do Body_A sao cavidades internas seladas (3 shells)
    - verify_geometry_ssot.py: detecta as cavidades seladas (2 nao conformidades)
    - SSOT e README atualizados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
2026-09-11 v28.0 (proposta DFM): chanfro 0,80x45 + land 9,20, pinos conjugados nas 2 metades, 6 cartuchos + 4 TCs, canal em 1 solido
    - gerar_matriz_v28.py: reconstroi apenas Z>=99 sobre o canal aprovado (funil
    herdado 1:1 do v27: distancia maxima entre superficies = 0,000000 mm) e abre
    os furos como vazios reais, sem cavidade selada
    - verificar_v28.py: 64 checagens medidas nos STEP (booleanos + BRepExtrema),
    64 conformes / 0 nao conformes; inclui fecho volumetrico (residuo 0,0115 mm3),
    parede real por furo (2,39-17,03 mm), web minima 5,380 mm e contagem de
    solidos por arquivo entregue (pegou bug real: os 3 STEP de montagem
    escreviam no mesmo nome)
    - explorar_acomodo_furos.py: mapeia o aco d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
    [MatrizJonatha_v28.step, MatrizJonatha_v28_Body_A.step, MatrizJonatha_v28_Body_B.step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]
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2026-09-12 mede a interface com o cabecote EX-030 e prove por booleanos (43 itens, 0 NC)
    O DWG 030-032 foi convertido e medido entidade por entidade. A escala saiu das proprias
    cotas do desenho: k = 25,534 mm/unidade DXF, com cinco fechos independentes batendo em
    0,012% (C.C Ø180, Ø220, Ø130, Ø95, Ø90). Isso corrige a leitura anterior ("C/G Ø150",
    k = 21,28), que vinha de raster em baixa resolucao.
    Cabecote medido: comprimento 95,00; corpo Ø130 × 42,00; flange Ø220 × 40,00 com ressalto
    Ø203 × 3,00; tres furos para a matriz - Ø80,00 × 14,00 / Ø90,00 × 11,00 / Ø95,00 × 70,00;
    anel da face de 20,00 mm (Ø90 -> Ø130); junta com a extrusora em 6 x Ø16,50 sobre C.C.
    Ø180,00 em fendas de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
2026-09-12 SSOT, relatorio DFM, README e AUTO_PROMPT sincronizados com a interface medida
    - novo bloco `interface_cabecote` no SSOT: numeros vindos de interface_cabecote.json
    ("fonte_numeros" aponta o gerador), inclusive areas e pressoes
    - F-28-1 (fixacao) passa a RESOLVIDA PELO CABECOTE com os numeros medidos; a recomendacao
    de grampos no flange e retirada e a "correcao" da escala errada fica registrada em F-28-3
    - F-28-6 (anel do nariz de 65 mm) e F-28-7 (curso/torque de aperto da bucha EX-031) abertos
    - fabricacao: banda Ø93 retificada na zona de aperto, degrau Z=69,90 com planicidade e
    perpendicularidade <= 0,01, bolsões de pino cegos (sem escarear) - ordem de usinagem atualizada
    - `gerar_r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
2026-09-12 v28.1: aplica D1/D2/D4 e a medicao do croqui; verificador passa a ler o labio do SSOT
    Decisoes do usuario (2026-09-11) gravadas em decisoes_usuario no SSOT:
    - D2: chanfro 1,50x45 e land 8,50 do MASTER mantidos (0,80 rejeitado).
    gerar_matriz_v28.py nao tem mais 9,20/0,80: le proposta_v28_dfm.geometria_labios.
    verificar_v28.py compara a lamina com decisoes_usuario.D2.geometria.lamina_mm=0,75.
    7 STEP da proposta regerados: land 8,500 / chanfro 1,500 / lamina 0,750 medidos, 64/64 conforme.
    - D1: fixacao = collete EX-031 + degrau do cabecote; matriz nao leva furo nem flange.
    - D4: nao promovida - MatrizJonatha.step segue v27.0, 02_CAD_Modelos_Historicos/ intacto.
    - Croqui: anel da face 20,0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
    [MatrizJonatha_v28.step, MatrizJonatha_v28_Body_A.step, MatrizJonatha_v28_Body_B.step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]
2026-09-12 D3 medida: funil coat-hanger modelado e comparado com o cone do master
    Estudo pedido pelo usuario antes de qualquer mudanca de canal. Nada promovido: o oficial
    segue v27.0 e a v28.1 segue proposta; o estudo fica em pasta propria.
    - 04_Dados_SSOT_e_Scripts/estudar_funis.py: refaz o loft POR TODAS AS ESTACOES (o bug do
    generate_true_coathanger_jonatha.py era interpolar so a 1a e a ultima secao) usando as
    secoes declaradas (circulo 75,60 em Z=0; slot 35x12 em Z=25; 75x3,5 em Z=70; 75x1,5 no
    land), e mede os dois solidos com a mesma trena (secao()/dp_total() do proprio projeto).
    - Numeros medidos: Delta-P 1D 100,9 bar (cabide) contra 41,9 bar (atual) = 2,41x;
    volume do canal 76.010 mm3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
    [ESTUDO_funil_coathanger_Canal_Fluxo.step, ESTUDO_funil_coathanger_Matriz.step]
2026-09-12 gerador: rotulo dos documentos passa a vir do SSOT (arquivos seguem MatrizJonatha_v28*)
    [MatrizJonatha_v28.step, MatrizJonatha_v28_Body_A.step, MatrizJonatha_v28_Body_B.step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]
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2026-09-12 cabeçote EX-030 em STEP sem a junta da extrusora (pedido do usuário), com as provas medidas
    gerar_cabecote_ex030.py reusa o construtor solido do verificador de interface (geometria 100%
    medida no DWG) e corta por intersecao com o cilindro Ø130 do corpo - a definicao de 'a parte que
    conecta na extrusora' sai de medida, nao de gosto: tudo que esta fora de r = 65,00 mm (cubo Ø164
    d 42..52, flange Ø220 x 40 d 52..92, resalto Ø203 x 3 d 92..95). Os 6 furos Ø16,5 em C.C. Ø180
    estao todos a r = 90 > 65, entao o corte leva a junta inteira sem abrir furo nenhum.
    medido no solido (06_CAD_Cabecote_EX-030/):
    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
    [Cabecote_EX-030_desenhado.step, Cabecote_EX-030_sem_flange.step]
2026-09-12 SSOT do cabeçote: protrusão 14,00 mm (não 14,3) e os dois degraus separados por 0,30 mm
    `referencia_axial.posicao_da_matriz` dizia "a matriz protrui 14,3 mm para fora da face do nariz".
    14,30 é onde está o degrau Ø89,5->Ø79,5 da matriz (Z=80,70 -> d=14,30), não o fim da protrusão:
    a protrusão é 109,00 - 95,00 = 14,00 mm, e a diferença de 0,30 mm entre as duas cotas é a folga
    axial do degrau do cabeçote (face medida em d = 14,02 no DXF). Cotas de faces diferentes, não a
    mesma lida duas vezes - agora está escrito assim no dado, para ninguém tentar "conciliar" os números.
    Cadeia re-rodada e idempotente: matriz 64/64, interface 48|41|1 NC|6 pend, STEP do cabeçote sem
    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
    [Cabecote_EX-030_desenhado.step, Cabecote_EX-030_sem_flange.step]
2026-09-12 collete EX-031: o furo medido é Ø90 reto e não passa sobre a banda Ø93 — pressão radial vira condicional
    Medindo as vistas do DXF cada uma com o SEU eixo (ate aqui eu varria tudo em torno do eixo do
    corte do cabecote, y = 0, e as outras vistas tem eixo proprio - por isso nada aparecia), aparece o
    que faltava: as UNICAS 4 geratrizes inclinadas do desenho inteiro estao a 3,267 deg, a silhueta
    delas e simetrica e mede 086,00 (a 0,01 mm, com a MESMA k = 25,534 calibrada em outra fecho - o
    que re-confirma a escala), e o furo que as acompanha e RETO 090,00 por 63 a 70 mm.
    Consequencia, e ela derruba um numero meu: com 090 reto o collete nao desce sobre a banda 093 da
    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
    [Cabecote_EX-030_desenhado.step, Cabecote_EX-030_sem_flange.step]
2026-09-12 estudo do recuo dos cartuchos (alternativa (a) da pendencia [F]) + correcao do volume de bloqueio
    Estudo (05_Variantes_Em_Estudo/ + ESTUDO_RECUO_CARTUCHOS.md), construido pelo caminho real do
    projeto - gerar_matriz_v28.construir() variando so o plano Z, medido com BRepExtrema e booleano
    contra o solido do cabecote medido no DWG. Nenhum arquivo oficial tocado:
    | cenario | Z | furo->canal | borda->face saida | web | bloqueio no cabecote | folga traseira | massa |
    | como esta | 97,00 | 8,196 | 7,250 | 5,380 | 2744,6 mm3 | -2,750 | 3,586 kg |
    | minimo que passa | 99,75 | 8,196 | 4,500 | 4,320 | 0 | 0,000 | 3,582 kg |
    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
    [ESTUDO_recuo_cartuchos_Z10025_Body_A.step, ESTUDO_recuo_cartuchos_Z10025_Body_B.step, ESTUDO_recuo_cartuchos_Z9975_Body_A.step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]
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2026-09-12 verificar_cadeia.py: porta unica que roda a cadeia e cobra 7 invariantes (auto-testada)
    Existe por causa de duas familias de erro que esta sessao produziu de verdade:
    - numero de booleano copiado a mao em documento e depois esquecido (o 1372,276 mm3 do bloco [F]
    que virou 2744,550 e o 'protrui 14,3 mm' que e 14,00 - os 0,30 sao a folga do degrau);
    - veredito confundido com crash: exit code 1 em verificar_interface_cabecote.py /
    verify_geometry_ssot.py significa 'ha nao conformes', e a porta agora exige o NUMERO esperado
    (1 e 2) lido do resumo, em vez de aceitar ou reprovar cegamente.
    Checagens: [1] a cadeia roda; [2] matriz 64/0; [3] interface com exatamente 1 NC e ele e o
    conhecido,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
2026-09-12 parte interna: as 5 matrizes medidas uma a uma contra a escada do cabeçote
    Medidor novo `04_Dados_SSOT_e_Scripts/medir_perfis_matrizes_x_cabecote.py`
    (+ `perfis_matrizes_x_cabecote.json` e o relatório
    `03_Relatorios_e_Documentacao/INTERFASE_INTERNA_CABECOTE_X_MATRIZES.md`),
    gerado a partir da medição - nenhum número do texto é digitado.
    O que a medição deu (escada por seccões de 0,20 mm, transições refinadas por
    bisseção a 0,005 mm, posicionamento por encosto e interferência por booleano):
    - A escada interna do cabeçote é o molde da Copo: bolso Ø95,00 × 70,00, degrau
    Ø90,00 × 11,00 (Z 70..81), nariz Ø80,00 × 14,00 (Z 81..95) e o rebaixo
    Ø105 × 3,00, que não res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
    [Cabecote_EX-030_desenhado.step, Cabecote_EX-030_sem_flange.step, MatrizJonatha_v28.step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]
2026-09-12 desenho 2D em PDF do par; encosto face a face gravado; e o modelo corrigido por ele
    Entrega do desenho 2D (06_CAD_Cabecote_EX-030/STEP/DESENHO_2D_CABECOTE_X_MATRIZ_COPO.pdf): vista
    lateral em corte pelo plano do eixo, em três faixas - cabeçote, Matriz 1 Copo e a montagem no mesmo
    referencial axial - com as cotas principais de cada peça em coluna, chamadas até a geratriz. As linhas
    NÃO são traçadas à mão: são a seção medida dos próprios STEP (booleano com semiespaço, faces planas
    unidas em arame e perfil varrido fatia a fatia), com as arestas reais do sólido por cima em cinza fino;
    os números vêm de cabecote_ex030.json + verificar_interface_cabecote.py (cabeçote) e
    perfis_ma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
    [Cabecote_EX-030_desenhado.step, Cabecote_EX-030_sem_flange.step, MatrizJonatha_v28.step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]
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2026-09-12 montagens em STEP, Gedeon no desenho 2D e o relato contra a auditoria
    STEP do cabecote (o que voce pediu: sem matriz, e com a original e com a Gedeon):
    `gerar_cabecote_ex030.py` agora alem dos dois solidos escreve dois arquivos compostos,
    `Cabecote_EX-030_com_Matriz_Copo.step` e `Cabecote_EX-030_com_Matriz_Gedeon.step` - 2 solidos no MESMO
    referencial axial (Z = 0 no plano mais traseiro), SEM booleano, para folga e interferencia serem medidas no
    CAD de quem recebe. As matrizes sao lidas de 02_/01_ sem modificar (regra 2) e unidas A U B quando a peca e
    bipartida, ou seja: o mesmo corpo que `medir_perfis_matrizes_x_cabecote.py` mede. Medido na saida do
    gerador: interferencia 0,0000 mm3 nos doi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
    [Cabecote_EX-030_com_Matriz_Copo.step, Cabecote_EX-030_com_Matriz_Gedeon.step, Cabecote_EX-030_desenhado.step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]
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2026-09-12 montagens sem booleano, e o que a medida diz das tres coisas vistas nos STEP
    Entrega corrigida (era defeito meu): o arquivo da montagem trazia a matriz unida A U B. A uniao e valida
    (BRepCheck True) e e com ela que a folga e medida, mas ela conserva as cascas internas seladas dos solidos de
    origem - e solido com casca interna e exatamente o que abre como "peca quebrada" em importador de STEP. Agora
    cada solido vai como esta no arquivo de origem: `com_Matriz_Copo.step` = 2 solidos, `com_Matriz_Gedeon.step` =
    3 (cabecote + Body_A + Body_B), todos validos ao reimportar ([1,1] e [1,3,1]). A interferencia passa a ser
    somada peca a peca e da o mesmo numero (0,0000 mm3 nos dois), porque as metades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
    [Cabecote_EX-030_com_Matriz_Copo.step, Cabecote_EX-030_com_Matriz_Gedeon.step, Cabecote_EX-030_desenhado.step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]
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2026-09-12 Prancha da Gedeon corrigida - e a causa da diferenca com a Jonatha, corrigida por medida
    `desenhar_gedeon_consertada.py` gera `06_CAD_Cabecote_EX-030/STEP/Gedeon_Corrigida/
    DESENHO_2D_GEDEON_CONSERTADA_X_JONATHA.pdf`: cinco faixas no MESMO escalonamento (limites identicos em todas,
    porque comparacao em escala diferente nao e comparacao), todas traçadas da seccao medida no solido, nenhuma cota
    decorada:
    1 cabeçote sem matriz · 2 Gedeon como entregue · 3 Gedeon reconstruída do seu backup · 4 Jonatha v27 ·
    5 onde as duas diferem (o booleano nos dois sentidos, re-cortado em Y = 0 - e o plano onde os bolsos de pino
    aparecem; em X = 0 eles somem da figura)
    Nas faixas 2 e 3, a mesma caixa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
    [Cabecote_EX-030_com_Matriz_Copo.step, Cabecote_EX-030_com_Matriz_Gedeon.step, Cabecote_EX-030_com_Matriz_Gedeon_Corrigida.step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]
2026-09-12 A matriz Gedeon certa e o arquivo do usuario, inteiro - a minha "corrigida" estava errada
    Ele mediu no visor 3D e disse o que os numeros ja diziam: `02_/matrizGedeonCerta.step` NAO e bloco bruto
    para re-cortar - e a matriz pronta. `gerar_gedeon_certa.py` mede o arquivo face por face e entrega sem
    tirar um decimo de aco dele:
    * 1 solido, 18 faces, 640.180,7 mm3, 3 cascas - e `valido` no BRepCheck
    * fenda de largura 75,00 x espessura 1,50 com R 0,75 nos dois topos, ATRAVESSADA de Z = 0,17 a
    Z = 109,00 (sai pela face de saida - a linha que se ve na face do visor 3D e ela)
    * cone de entrada abrindo em Ø 75,60 na face traseira, fechando em Z = 20,98 - o Ø da restricao do
    contrato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
    [Cabecote_EX-030_com_Matriz_Gedeon_Certa.step, Cabecote_EX-030_com_Matriz_Gedeon_Corrigida.step, MatrizGedeon_Certa_Body_A.step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]
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2026-09-13 Os dois verificadores ainda liam a v28 da pasta do master - consertado, e o peso medido da reorganizacao
    Dois joins usavam a constante de pasta com uma variavel de nome, `os.path.join(DIR_CAD, nm)`, entao o
    `verificar_v28.py` foi buscar `MatrizJonatha_v28_Explodida.step` dentro de M01 (o master) e morreu em
    "STEP File could not be loaded". Meu codemod so reconhecia o literal `"MatrizJonatha_v28..."` na linha, nao
    o nome vindo de um dicionario - falha minha, pega pelo portao completo, nao por olhada no codigo. Agora os
    dois arquivos (verificar_v28 e renderizar_v28) resolvem a pasta pelo nome: `_v28` no nome ->
    M02_Jonatha_v28_PROPOSTA, o resto -> M01_Jonatha_v27_OFICIAL.
    Correcao de um numer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
    [Cabecote_EX-030_com_Matriz_Copo.step, Cabecote_EX-030_com_Matriz_Gedeon.step, Cabecote_EX-030_com_Matriz_Gedeon_Corrigida.step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]
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2026-09-13 reorganização #2: uma pasta por matriz, sem camada intermediária; Gedeon "corrigida" apagada
    `07_CAD_Matrizes/` passa a ter 6 pastas, uma por matriz, cada uma com os arquivos dela dentro:
    `Matriz_Jonatha_v27_OFICIAL`, `Matriz_Jonatha_v28_1_PROPOSTA`, `Matriz_Gedeon_Certa`,
    `Matriz_Gedeon_Entregue_HISTORICA`, `Matriz_Copo_HISTORICA`, `Matriz_Desenvolvimento_HISTORICA`. Caiu o
    aninhamento `M01..M06` e caíram as três pastas que só tinham ponteiro — era isso que estava errado.
    * Os STEP históricos saíram de `02_CAD_Modelos_Historicos/` para a pasta da matriz correspondente e `02_/`
    manteve atalho com os mesmos bytes (`git ls-files -s 02_/` mostra 120000 em cada linha). A regra 2 do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
    [Cabecote_EX-030_com_Matriz_Gedeon_Certa.step, Matriz1_Original_Copo.step, Matriz1_Original_Copo_Body_A.step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]
2026-09-13 atalhos de 01_/ consertados, README/CONTINUIDADE na estrutura nova, .gitignore com os nomes atuais
    * Os 6 atalhos de `01_CAD_MatrizJonatha_Oficial/` apontavam para `../../07_...` (um nível a mais, herança do
    aninhamento `M0x` que caiu): `os.path.realpath` resolvia para fora do repo e o portão morria com
    `FileNotFoundError` na checagem da regra 1. Corrigidos para `../07_CAD_Matrizes/Matriz_Jonatha_v27_OFICIAL/`;
    o sha256 do master bate o baseline (`7f26c5c5ba238a12…`) e a regra 1 passa a conferir por conteúdo também.
    * `CONTINUIDADE.md` na raiz (novo) + ponteiro no `README.md`: estado do trabalho, as regras 1-7, como montar o
    ambiente (`pip install cadquery` + `LD_LIBRARY_PATH`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
    [Cabecote_EX-030_com_Matriz_Copo.step, Cabecote_EX-030_com_Matriz_Gedeon.step, Cabecote_EX-030_com_Matriz_Gedeon_Certa.step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]
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2026-09-13 as quatro decisões novas entram no SSOT e no AUTO_PROMPT — e a auditoria v1.0 é declarada encerrada
    `decisoes_usuario` em `04_Dados_SSOT_e_Scripts/cad_die_parameters.json` ganha D5..D8, e
    `generate_auto_prompt.py` passa a conhecê-las (o prompt de handover continua sem nada digitado à mão: sai do
    SSOT). Registrado por escrito, que é para a próxima IA não "descobrir" que dá para reabrir:
    * **D5** — a Gedeon certa é o arquivo dele; a "Gedeon corrigida" foi refutada por medida e apagada por inteiro.
    * **D6** — uma pasta por matriz, sem camada intermediária e sem pasta só com ponteiro; `01_/` e `02_/` são
    atalhos porque as regras 1 e 2 falam dos modelos, e o baseline selou c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
2026-09-13 CONTINUIDADE e README das ferramentas: a main recebeu o estado por ordem direta dele, nao pelo rito de veredito (nao e aprovacao da v28); tabela dos scripts corrigida (7, nao 8)
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2026-09-13 montagens: uma versao de CADA matriz dentro do cabecote COMPLETO com flange (6, nao 2)
    Ele pediu em 2026-09-13: "uma versao de cada matriz dentro do cabecote completo com flange". O gerador ja
    montava so Copo e Gedeon; MONTAGENS passa a ter as seis (Copo, Gedeon entregue, Gedeon CERTA,
    Desenvolvimento, Jonatha v27, Jonatha v28.1), todas sentadas no `Cabecote_EX-030_desenhado.step` - que e o
    cabecote completo: corpo D130 + chanfro 10x45 + flange D220x40 com os 6 furos M12 + junta. Cada montagem e
    entregue sem booleano (1 cabecote + N solidos da matriz, no referencial axial do projeto), com a
    interferencia medida peca a peca, a face de saida e a protrusao alem da face do nariz; e o JSON passa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
    [Cabecote_EX-030_com_Matriz_Copo.step, Cabecote_EX-030_com_Matriz_Gedeon.step, Cabecote_EX-030_desenhado.step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]
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2026-09-13 seis montagens com flange no disco: Copo, Gedeon entregue, Gedeon CERTA, Desenvolvimento, v27 e v28.1
    `python3 04_Dados_SSOT_e_Scripts/gerar_cabecote_ex030.py` (com o medidor de perfis re-rodado antes para gerar o
    encosto da Gedeon CERTA). Cada arquivo e o cabecote COMPLETO (`Cabecote_EX-030_desenhado.step`: corpo Ø130 +
    chanfro 10×45 + flange Ø220×40 com os 6 furos M12 + junta) com a matriz sentada, sem booleano nenhum, e a
    medicao saiu assim:
    | montagem | solidos | interferencia | saida da matriz | protrusao |
    |---|---|---|---|---|
    | `Cabecote_EX-030_com_Matriz_Copo.step` | 2 | 0,0000 mm³ | Z 80,70 | −14,30 mm (recesada) |
    | `Cabecote_EX-030_com_Matriz_Gedeon.step` | 3 | 0,0000 mm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
    [Cabecote_EX-030_com_Matriz_Copo.step, Cabecote_EX-030_com_Matriz_Desenvolvimento.step, Cabecote_EX-030_com_Matriz_Gedeon.step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]
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2026-09-13 PRs: fechamento registrado no CONTINUIDADE, e a verdade do estudo M12 corrigida no mesmo passo
    Ele mandou fechar todas as PR (tres vezes, sem ambiguidade). Feito pela API, com comentario antes de fechar, e
    verificado depois: `total PR: 4 | ABERTAS: nenhuma`, com a **#4 fechada sem mesclar** (`merged_at = null`) e sem
    re-veredito nenhum — o metodo v1.0 esta encerrado por ordem dele, nao reaberto. Branch da #4 no disco do GitHub
    esta intacta e `delete_branch_on_merge=false`, entao reabrir ou mesclar e um comando dele.
    No mesmo commit, dois trechos do `CONTINUIDADE.md` que tinham virado mentira com a rodada da tarde: o item 5
    dizia que o estudo da furacao M12 "fica no disco em `06_/STEP/estu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
2026-09-22 pacote: e-mail de primeiro contato ao fornecedor (07_) + CHECKSUMS com 15 arquivos
    08_Pacote_Usinagem_v29/07_EMAIL_DE_PRIMEIRO_CONTATO.md - a carta de capa para o fornecedor: assunto,
    corpo com a tabela do que ele precisa para orcar (peca unica sem furo de fixacao, 1.2344 50-52 HRC com
    alivio de tensoes antes da tempera, fenda 75,00 x 1,500 +0,010/-0,000 com raios R 0,75, assentamento
    0/-0,02 e coaxialidade 0,02 em A, Ra 0,4 sem revestimento, dosse com CMM e certificado 3.1), cinco
    perguntas de capacidade que definem quem orca (fio EDM da fenda pos-tempera, T.T. interno ou
    terceirizado e compensacao de retracao, prazo e preco 1/4/5, dosse, sigilo), uma versao de quatro linhas
    para o primeiro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
2026-09-23 pacote: as tres linhas de Ø estavam saindo com 93,00/89,50/79,50 - corrigido
    Achei o erro relendo o documento gerado, nao o codigo: minha troca de linhas da
    tabela casava by item[:9].startswith("Diâmetro do 1") - "Diâmetro do 1" tem 12
    caracteres, entao nenhum prefixo de 9 casas comeca assim e as tres linhas de
    envelope passaram ilesas com o Ø velho e com a frase "folga de 1,00 mm / anel de
    0,25 mm", que e justamente o que a folga nova (0,50 nos tres estagios) desmentiu.
    O resto da tabela tinha saido certo (comprimento, dureza, marcacao, tratamento),
    o que deixava o documento internamente incoerente - o pior tipo de erro para a
    fabrica ler.
    Agora as linhas 1-3 saem com o Ø medido no ST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
2026-09-25 matrizaria 23-24/09 lida e registrada; DXF cotado ganha gemeo AC1015
    Contato com a matrizaria (Fernando Fugulin) consolidado em
    03_Relatorios_e_Documentacao/CONTATO_MATRIZARIA_FERNANDO_2026-09-24.md:
    o que e texto literal de chat, o que e audio transcrito por maquina e o que
    e legenda de IA sobre foto. Ele nao abriu os STEP no celular e pediu DWG/DXF
    (24/09 10:01, pedido ainda nao atendido); os nossos STEP sao ASCII
    ISO-10303-21 com 0 byte nao-ASCII, conferido no binario. Diagnostico dele:
    desequilibrio de fluxo, e "o projeto de voces nao vai resolver"; os 4
    recursos que ele propoe, o alerta de que nao ha recurso depois de cônico e a
    decisao A/B (freio na matriz atual x fabricar a v30) fica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
    [MATRIZ_V29_DESENHO_COTADO_AC1015.dxf, MATRIZ_V30_DESENHO_COTADO_AC1015.dxf]
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2026-09-25 avaliacao da v30 contra o veredito da matrizaria: ela nao equilibra fluxo, e os numeros sao nossos
    Ele pediu avaliacao franca: a v30 veio da bipartida convertida em peca unica
    e o Fernando acha que nao resolve o serrilhado. Novo
    03_Relatorios_e_Documentacao/AVALIACAO_V30_X_FLUXO_2026-09-25.md, escrito so
    com o que o repo ja media e re-rodado nesta rodada (sem memoria):
    - veredito: ele esta certo no essencial. Funil conico + land de largura
    constante nao redistribuem vazao na largura; o unico mecanismo que faria isso
    (altura das asas decrescente do centro para as pontas) ja estava diagnosticado
    no D3 com custo medido de +141% de DeltaP, e a D3 diz que nao muda a
    espessura em um micro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
2026-09-25 2ª medicao na linha, agora com balanca: perfil confirmado e a flecha do sorriso
    Espessura 1,50/2,50/2,50/2,00/1,50 mm e massa 0,80/1,30/1,40/1,10/0,80 g nos
    y = -37,5/-18,75/0/+18,75/+37,5. m/t nas cinco estacoes: media 0,539 g/mm com
    desvio-padrao de 2,9%, e o afastamento maximo entre os dois metodos e 7,1%.
    Ou seja: o perfil nao e o paquimetro afundando no mastique - os dois metodos
    contam a mesma historia. Novo 03_/MEDIDA_2_PERFIL_E_PESO_2026-09-25.md.
    Secao integrada pelos 5 pontos: 159,4 mm2 contra 112,5 mm2 nominais (+42%), o
    que com Q = 15.000 mm3/s sai a 5,6 m/min em vez de 8,0. Enquadramento em que
    eu mesmo me corriji no caminho: com a vazao fixada pela rosca ele nao esta
    queimand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
